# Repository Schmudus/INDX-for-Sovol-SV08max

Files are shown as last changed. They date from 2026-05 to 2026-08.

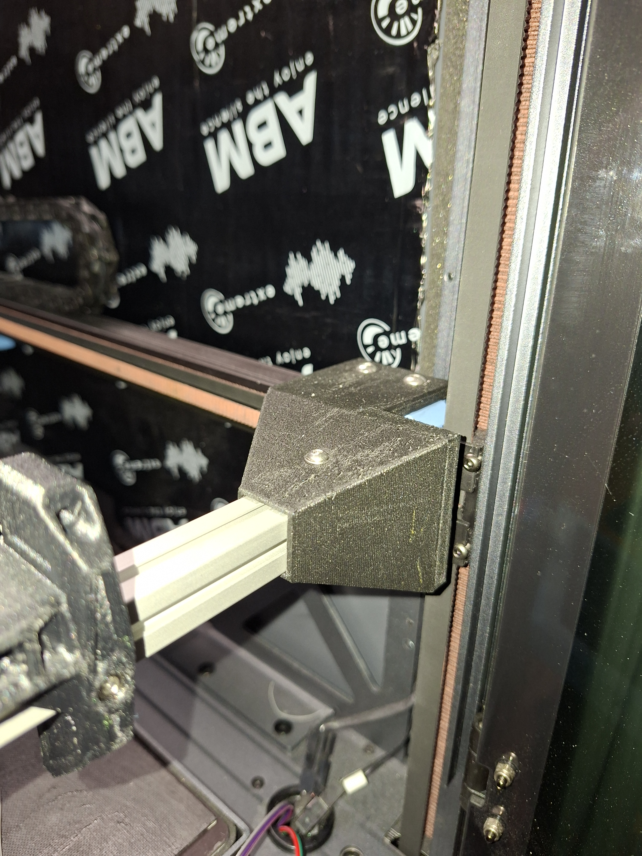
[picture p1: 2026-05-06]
Pictures/15151.jpg

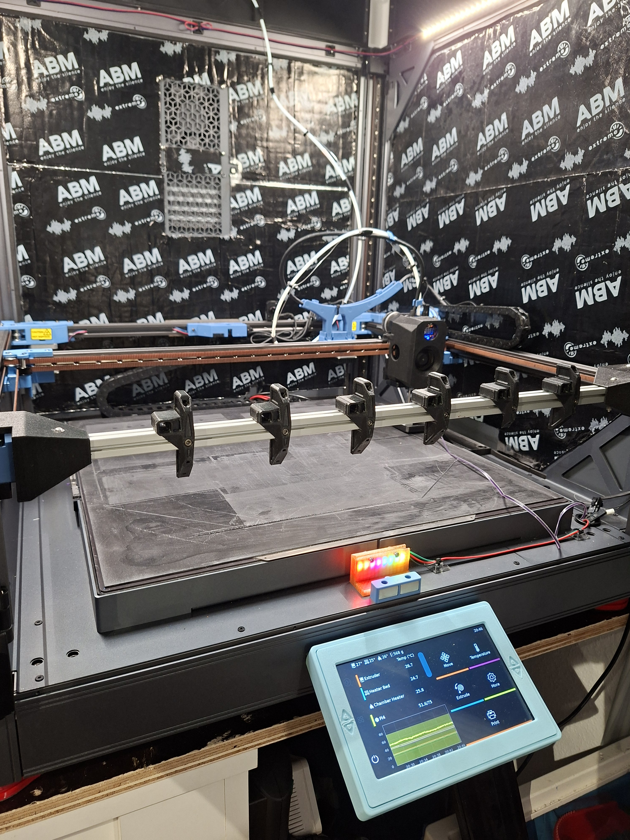
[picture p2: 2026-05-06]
Pictures/15153.jpg

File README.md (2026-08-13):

# INDX for Sovol SV08max
## Modification necessary to the Sovol SV08max
My printer has modificated electronics. The following may not be applicable to standard SV08max!

## Bed height
To fit INDX toolhead it is necessary to raise the bed about 12mm. I did this with 12mm silicon spacer (e.g. Creality use them) and put one washer under and over them. I glued the washer to the silicon and glued the part then to the SV08max frame (after lifting the aluminum plate). Loosen the 8 screws and lift the bed to the right side (cable is back right).
You will need some longer screws:
4 piece M5 x 55 (flathead)
4 piece M5 x 30 (flathead)

## 1515 extrusion for nozzle dock
To park/store the nozzles it is necessary to provide a 1515 extrusion in front of the printer. I made a simple, non-adjustable holder for it. It is mounted on the flying gantry.
The camera need to move away. Just unscrew it (one screw), pull the cable gently out of the right extrusion and place it in the back. There are 2 possible positions at the back gantry where already threads are placed. 

## X-axis limit switch
To use INDX it is necessary to find another limit switch position for X-Axis. The INDX toolhead have a plug for limit switch but (depending on your setup) not have any space to add aswitch.
Therefore I moved it to the right side of the gantry. 
I use a D2F-JO1F switch with a D2F to JST board (source: trianglelab).

## Nozzle offset determination
Nudge or camera is recommended while camera is already implemented in INDX macros.
To use nudge I made a holder for nudge which is screwed instread of the right handle in the printer. After determination the nozzle offsets you need to dismantle the holder.
It is necessary to print some spacer because of the changed bed height. The nudge plate should sit good fixed on the printer bed to avoid wrong measurement.

## Top riser
Thx to Clutch Kick for the design with smooth outet walls.
I did some changes for installation of INDX:
- Closed the original PTFE routing in the right back part
- Remake the back middle part:
  - 6 holes for PTFE routing and one bigger for CPAP hose (SV08max TopHat smooth middle back PTFE) 
  - same as before but with 6 openings for stainless spring steel 7.5x0.5mm (SV08max TopHat smooth middle back PTFE+spring steel) --> EDIT: It looks like it will be better to have the spring steel on the other side (below PTFE instead of above)
- Holder for the PTFE tube with spring steel 7.5x0.5mm (PTFE springsteel holder)

## Config files
Files moved to Klipper backup in: https://github.com/Schmudus/SV08max/tree/main/printer_data/config
Files and config are still in work but some parts can be used as example how it works.
Installed latest
- Kalico
- Axiscope
- Shake 'n' tune
- Sonar
- Timelapse
- LED effect
- INDX configuration files (INDX is implemented in Kalico, no installation necessary)

## Changes in my INDX config files
Code change:
Added following pull requests:<br>
https://github.com/BondtechAB/INDX/pull/4<br>
https://github.com/BondtechAB/INDX/pull/11<br>
https://github.com/BondtechAB/INDX/pull/13<br>
https://github.com/BondtechAB/INDX/pull/28<br>
https://github.com/BondtechAB/INDX/pull/33<br>

Will solve following issues as well:<br>
https://github.com/BondtechAB/INDX/issues/5<br>
https://github.com/BondtechAB/INDX/issues/16<br>
https://github.com/BondtechAB/INDX/issues/19<br>
https://github.com/BondtechAB/INDX/issues/30<br>

Added: Heating nozzle to 150°C (adjustable) while CAL_Z to have a better offset measurement.
Move Z before XY move (park) while tool change to avoid any scrapping on the printed part.
Move XY first before Z (back to print area) to avoid any scrapping on the printed part.

Added simple Spoolman support:
Fill in your spool ID in ```index.cfg``` under ```[gcode_macro _Filament]```

Added simple heat capacity per tool:
Fill in your measured heat capacity from macro LOAD_FILAMENT in ```index.cfg``` under ```[gcode_macro _Filament]```

## Disclaimer
THE FILES IN THIS REPOSITORY ARE PROVIDED "AS IS", WITHOUT WARRANTY OF ANY KIND, EXPRESS OR IMPLIED, INCLUDING BUT NOT LIMITED TO THE WARRANTIES OF MERCHANTABILITY, FITNESS FOR A PARTICULAR PURPOSE AND
NONINFRINGEMENT. IN NO EVENT SHALL THE AUTHORS BE LIABLE FOR ANY CLAIM, DAMAGES OR OTHER LIABILITY, WHETHER IN AN ACTION OF CONTRACT, TORT OR OTHERWISE, ARISING FROM, OUT OF OR IN CONNECTION WITH 
THE FILES IN THIS REPOSITORY OR THE USE OR OTHER DEALINGS IN THE FILES IN THIS REPOSITORY.
THE FILES IN THIS REPOSITORY ARE OPEN SOURCE.

## Links
https://www.bondtech.se/indx-by-bondtech/ </br>
https://github.com/BondtechAB/INDX </br>
https://github.com/zruncho3d/nudge </br>
https://github.com/Sovol3d/SV08MAX </br>
https://oshwa.org/resources/open-source-hardware-definition/ </br>
https://www.printables.com/model/1456462-sv08max-riser-for-stock-enclosure-smooth-outer-wal </br>
https://github.com/nic335/Axiscope </br>
https://github.com/julianschill/klipper-led_effect </br>

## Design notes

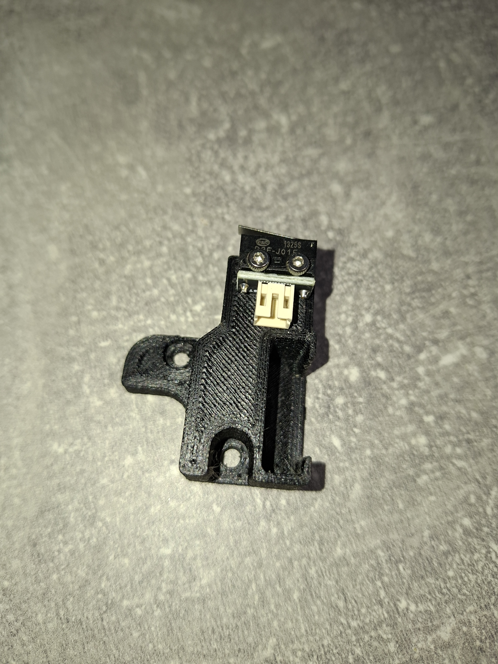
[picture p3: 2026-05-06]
Pictures/x limit 1.jpg

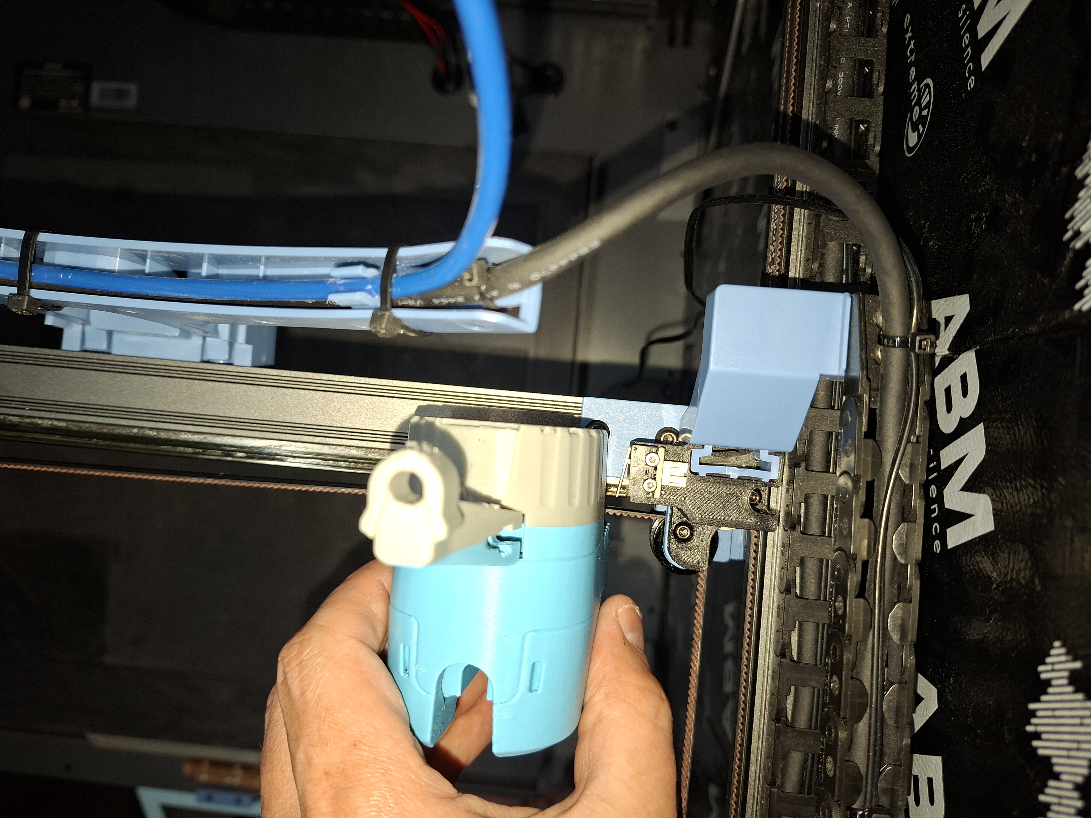
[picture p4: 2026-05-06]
Pictures/x limit 5.jpg

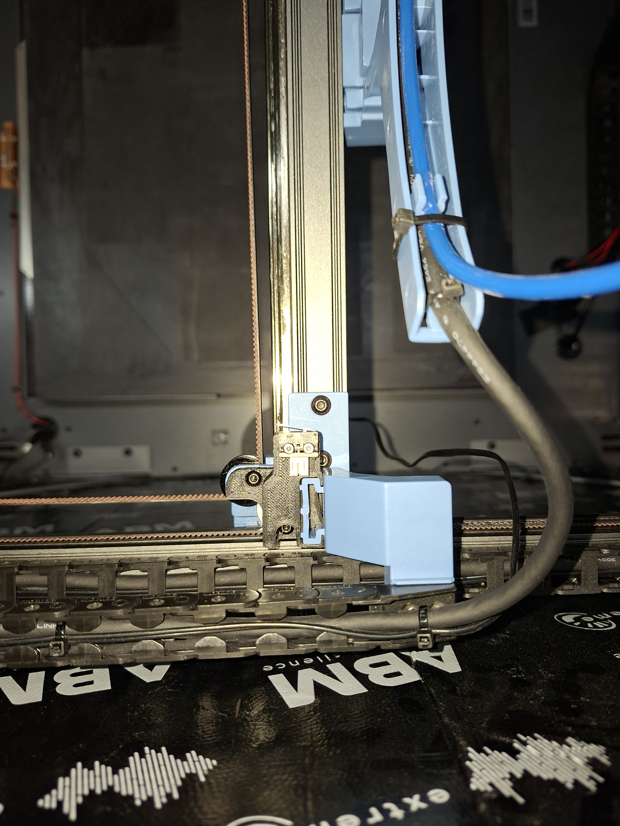
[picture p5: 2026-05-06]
Pictures/x limit 3.jpg

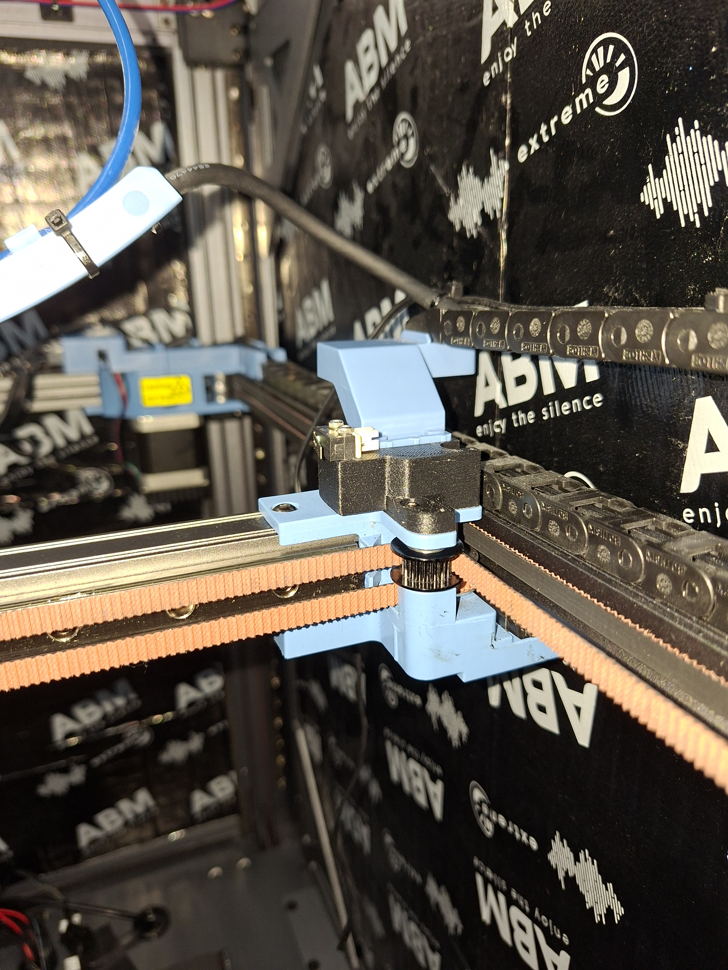
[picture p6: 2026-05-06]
Pictures/x limit 4.jpg

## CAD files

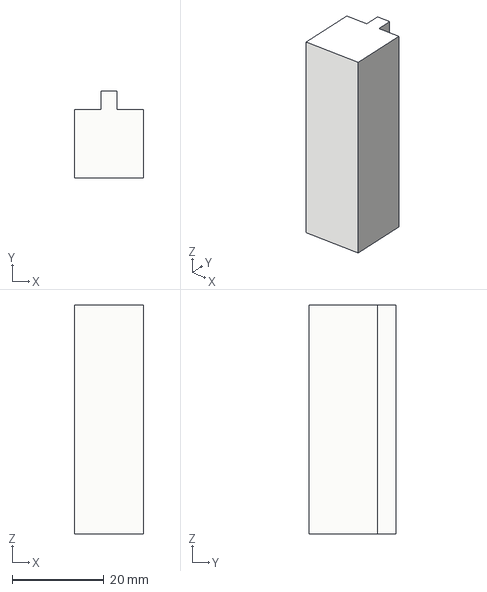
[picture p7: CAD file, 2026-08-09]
CAD/Helper.step
15.0 x 19.0 x 50.0 mm

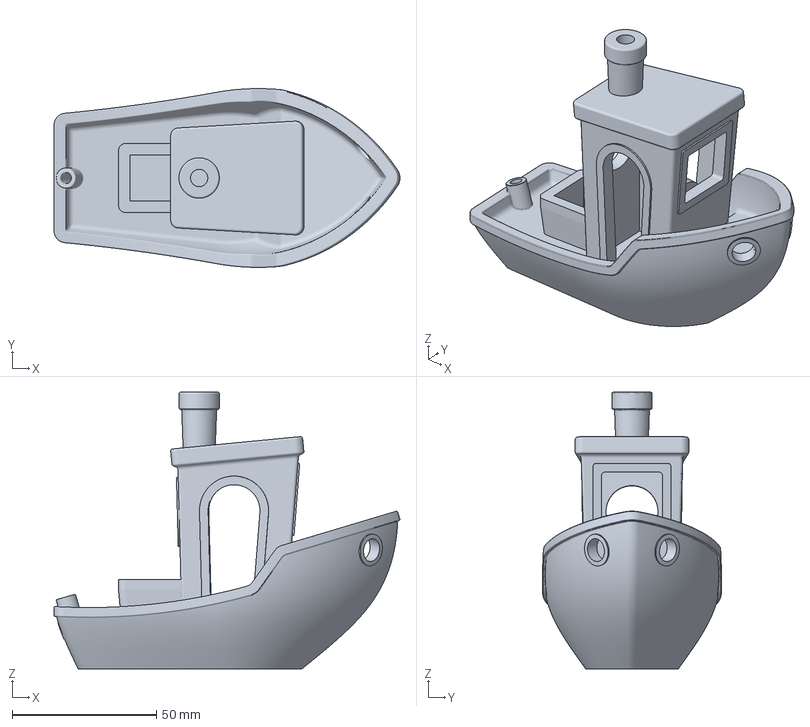
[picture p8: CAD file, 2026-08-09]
CAD/3dbenchy 6 color SV08max.3mf
120.0 x 62.0 x 96.0 mm

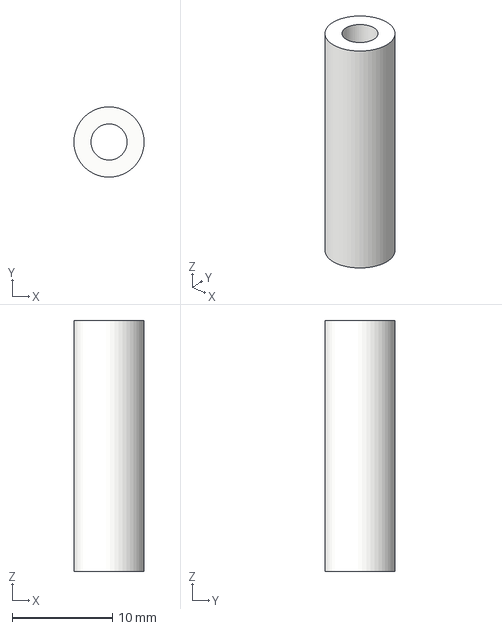
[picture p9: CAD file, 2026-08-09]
CAD/Abstandshalter 25.step
6.99 x 7.00 x 25.0 mm

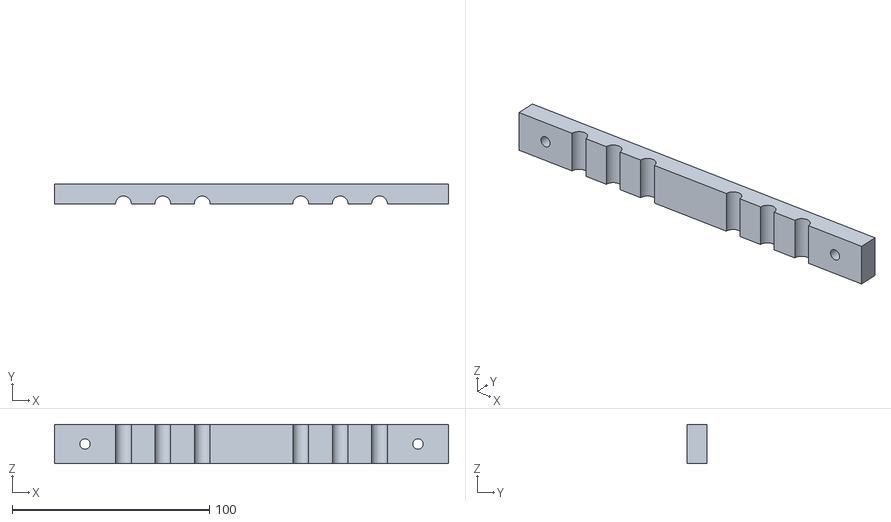
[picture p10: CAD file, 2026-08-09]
CAD/INDX Roof PTFE Holder.stl
200.0 x 10.0 x 20.0

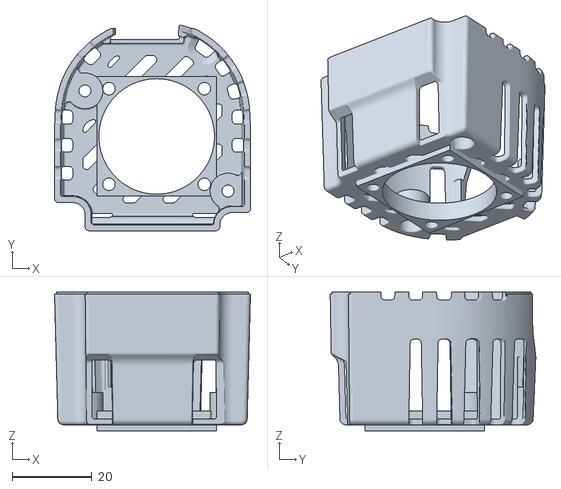
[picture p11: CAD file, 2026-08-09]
CAD/INDX PCB cover with fan 3030.stl
49.2 x 51.6 x 34.8

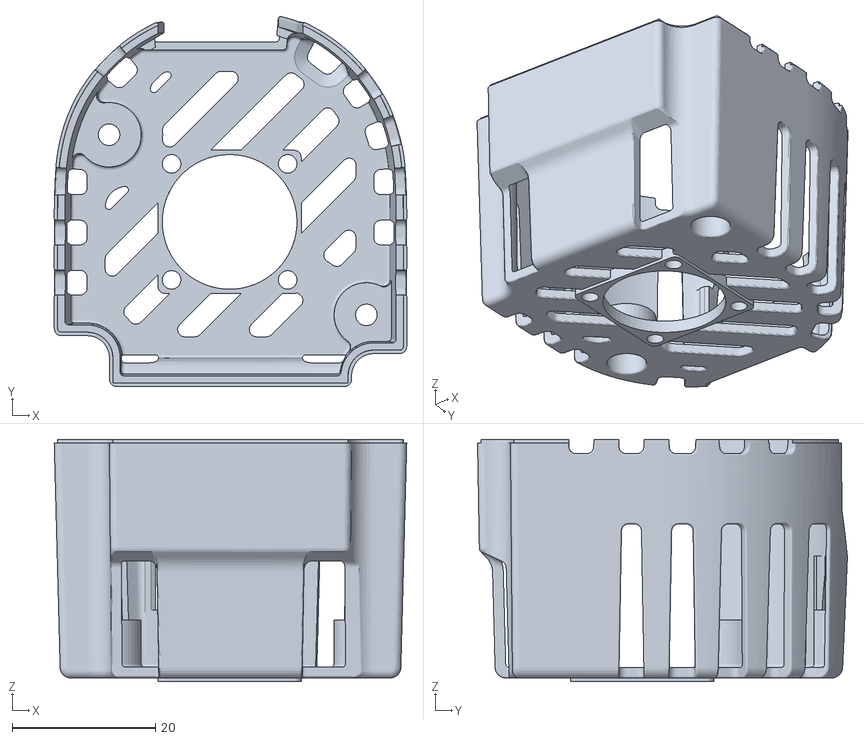
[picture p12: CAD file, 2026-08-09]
CAD/INDX PCB Cover with fan 2020.stl
49.2 x 51.6 x 33.8

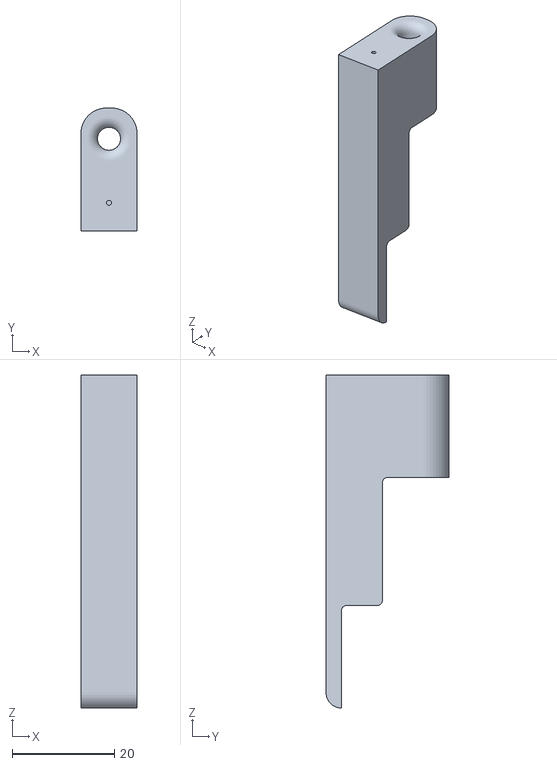
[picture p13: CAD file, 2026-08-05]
CAD/INDX PTFE Holder.stl
11.0 x 24.0 x 65.0

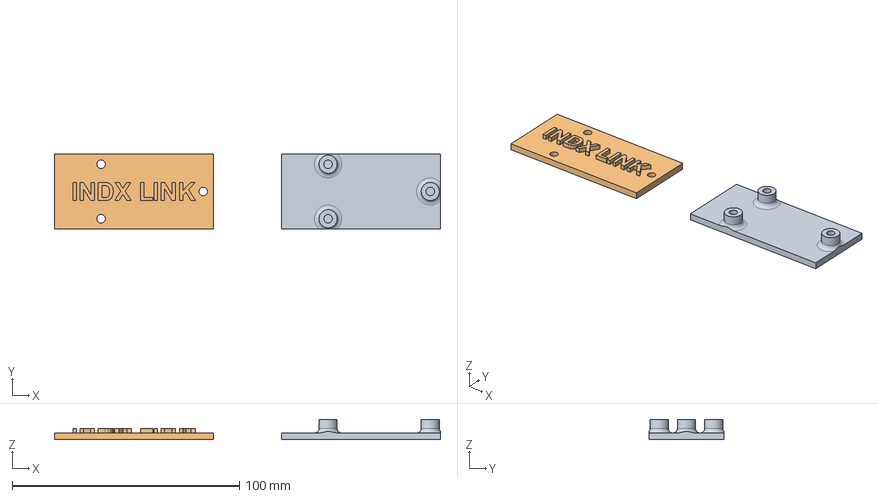
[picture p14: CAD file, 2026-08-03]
CAD/INDX link board mount.step
170.0 x 33.0 x 9.00 mm

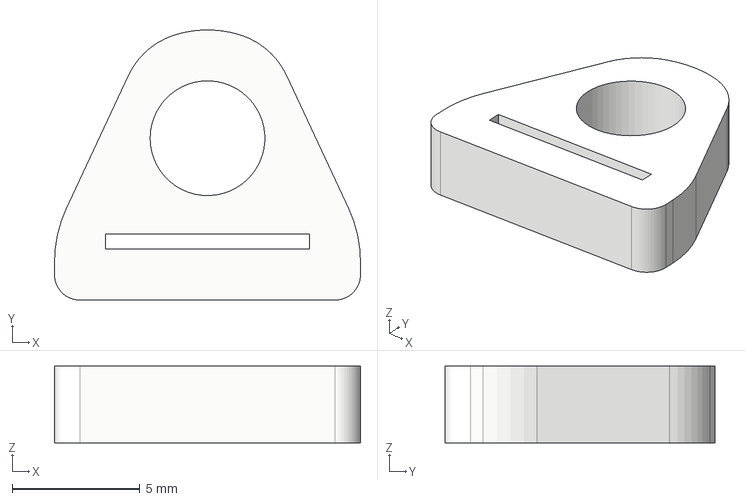
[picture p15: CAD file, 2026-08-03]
CAD/PTFE Federbandstahl holder.step
12.0 x 10.6 x 3.00 mm

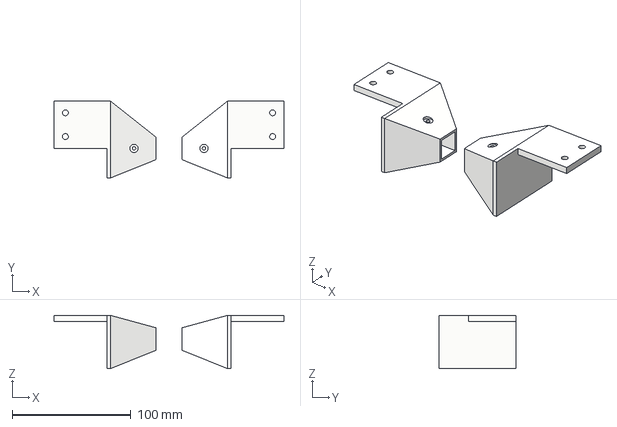
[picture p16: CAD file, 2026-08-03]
CAD/SV08max 1515 holder rev7.step
194.0 x 65.0 x 45.0 mm

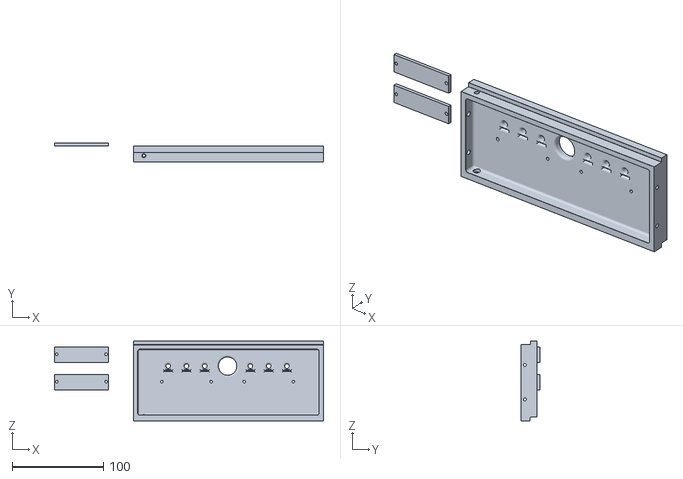
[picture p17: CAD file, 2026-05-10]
CAD/SV08max TopHat smooth middle back PTFE+spring steel v9.stl
294.4 x 20.7 x 87.5

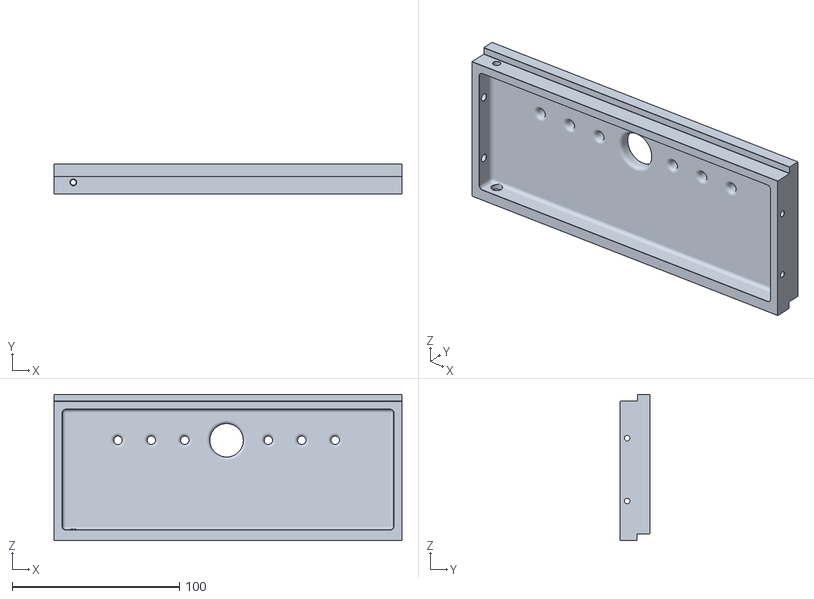
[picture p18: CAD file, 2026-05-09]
CAD/SV08max TopHat smooth middle back PTFE.stl
208.2 x 17.7 x 87.5

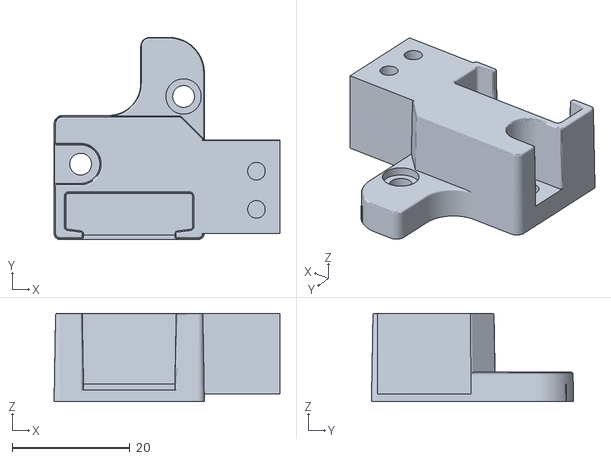
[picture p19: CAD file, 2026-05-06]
CAD/SV08max X limit switch v0.stl
38.4 x 34.4 x 15.0

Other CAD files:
CAD/PTFE springsteel holder.stl

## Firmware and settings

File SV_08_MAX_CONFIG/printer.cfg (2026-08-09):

[include indx.cfg]
[include indx-tc-macros.cfg]
[include indx-cal.cfg]

[mcu indxmcu]
serial: /dev/serial/by-id/usb-Bondtech_INDX*******  # fill in your adress
restart_method:command

### uncomment ONLY if you don't have already an [save_variable] entry in your printer.cfg ###
#[save_variables]
#filename: /home/pi/printer_data/config/variables.cfg

[indx]
mcu: indxmcu

# These are control parameters for the induction heater — leave them at these values
pid_kp: 1.0
pid_ti: 0.0
pid_td: 0.0
pid_b: 1.0

[gcode_button endstop]
pin: ^indxmcu:endstop
press_gcode: {action_respond_info("press")}
release_gcode: {action_respond_info("release")}

[lis2dw]
# Built-in accelerometer on the INDX PCB — used for input shaper calibration
i2c_mcu: indxmcu
i2c_bus: sercom3

[angle indx]
# Magnetic encoder that reads extruder rotation — used for precise extrusion monitoring
sensor_type: as5047d
stepper: extruder
cs_pin: indxmcu:encoder_cs
spi_bus: sercom1

### INDX loadcell ###
[load_cell_probe]
sensor_type: ads131m02
cs_pin: indxmcu:loadcell_cs
spi_bus: sercom1
data_ready_pin: indxmcu:loadcell_drdy
z_offset: 0
channels: 0
force_safety_limit: 0
trigger_force: 150
speed: 2
pullback_distance: 0.2
pullback_speed: 0.3
samples: 1
sample_retract_dist: 0.25
samples_tolerance: 0.05
samples_tolerance_retries: 3
sample_rate: 500

[resonance_tester]
accel_chip: lis2dw
probe_points:
    250, 250, 30  
accel_per_hz: 75

[extruder]
sensor_type: indx
min_temp: 0
min_extrude_temp: 180
max_temp: 350
heater_pin: indx:heater
control: watermark
nozzle_diameter: 0.4
filament_diameter: 1.75
step_pin: indxmcu:motor_step
dir_pin: indxmcu:motor_dir  # If filament feeds backwards, change to: !indxmcu:motor_dir
enable_pin: !indxmcu:motor_enable
microsteps: 32
rotation_distance: 5.7
max_extrude_only_distance: 250
max_extrude_cross_section: 60
pressure_advance: 0.020
pressure_advance_smooth_time: 0.020

[tmc2240 extruder]
cs_pin: indxmcu:motor_cs
spi_software_sclk_pin: indxmcu:motor_sclk
spi_software_mosi_pin: indxmcu:motor_mosi
spi_software_miso_pin: indxmcu:motor_miso
rref: 24000  # Reference resistor value for the TMC2240 on the INDX PCB — do not change
run_current: 0.6

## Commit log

2026-05-06 Change folder name
    [SV08max 1515 holder rev4.dwg, SV08max 1515 holder rev4.f3d, SV08max 1515 holder rev4.step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]
2026-05-09 Update README.md
    Added riser mod and spring steel/PTFE parts
2026-08-03 Add files via upload
    Revision 7 added.
    [INDX PTFE Holder.step, INDX link board mount.step, PTFE Federbandstahl holder.step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]
2026-08-05 Sovol SV08max - Config files added
    [beacon.cfg, bed_screws.cfg, bed_screws_all.cfg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]
2026-08-05 Update INDX PTFE Holder drawings
    [INDX PTFE Holder.step, INDX PTFE Holder.stl]
2026-08-05 Updated configs
    [beacon.cfg, indx-tc-macros.cfg, macro.cfg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]
2026-08-08 Create Moved to
    Config files now in my SOVOL SV08MAX.
    Automated update via Klipper backup.
2026-08-09 Config moved to different respository
    [beacon.cfg, bed_screws.cfg, bed_screws_all.cfg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]
2026-08-09 Added a printer.cfg with only the new parts for INDX
    [printer.cfg]
